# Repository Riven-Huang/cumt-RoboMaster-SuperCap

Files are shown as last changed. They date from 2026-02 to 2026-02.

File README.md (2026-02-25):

<div align="center">



[]()
[]()

**双向拓扑超级电容管理系统** | Bidirectional Buck-Boost Super Capacitor Management System

</div>

## 项目简介

本项目是中国矿业大学（CUMT）Cubot战队为RoboMaster比赛设计的**双向拓扑超级电容管理系统**。该系统用于舵轮步兵与摩擦轮英雄机器人，旨在提高规则允许下的闲置功率利用率。

---

## 🏗️ 硬件说明

### 📦 硬件实物图

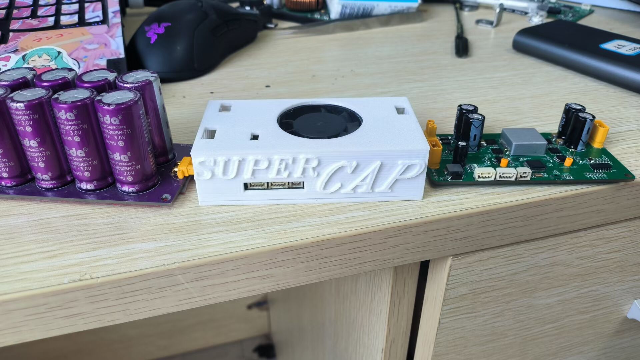
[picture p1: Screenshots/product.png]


### 核心功能

- **双向DC-DC转换**: Buck-Boost拓扑，支持充电和放电模式
- **功率管理**: 多环PID控制（电压环、电流环、功率环）
- **智能模式切换**: 基于占空比的平滑模式切换
- **CAN通信**: 与RoboMaster主控板实时通信
- **故障保护**: 过压、欠压、过流、短路保护

### 技术规格

| 参数 | 规格 |
|---|---|
| 主控芯片 | STM32F334C8Tx |
| PWM频率 | HRTIM 46.08kHz |
| 输入电压 | 24V (电池) |
| 电容电压 | 26V (目标) |
| 最大充电功率 | 200W |
| 控制方式 | 数字控制 (PID) |

---

## 2. 许可证说明

本项目采用 **CERN-OHL-S v2** (CERN Open Hardware Licence - Strongly Reciprocal) 开源许可证。

### 2.1 许可证权利

- ✅ 可自由使用、复制、修改本项目
- ✅ 可用于商业产品开发
- ✅ 可分发本项目及其衍生产品

### 2.2 许可证义务

- ⚠️ 分发时必须使用相同的 CERN-OHL-S v2 许可证
- ⚠️ 如果创建基于本项目的衍生产品，必须开源源代码
- ⚠️ 不得使用CERN的名称或标识进行商业背书
- ⚠️ 本项目按"原样"提供，无任何担保

### 2.3 第三方组件

| 组件 | 许可证 | 说明 |
|---|---|---|
| STM32 HAL库 | BSD-3-Clause | ST官方提供 |
| CMSIS | Apache 2.0 | ARM官方提供 |

---

## 3. 项目结构

```
cumt-RoboMaster-SuperCap/
├── LICENSE                    # CERN-OHL-S v2 许可证全文
├── README.md                  # 项目说明
│
├── Code Project/              # 代码项目
│   └── CAP_Code钳位/
│       ├── Core/              # CubeMX生成代码
│       │   ├── Inc/           # 头文件
│       │   └── Src/           # 源文件 (main.c, adc.c, can.c, etc.)
│       ├── MDK-ARM/           # Keil工程
│       │   └── bsp_user/      # 用户驱动层
│       │       ├── function.c/h   # 核心控制逻辑
│       │       ├── drv_can.c/h    # CAN通信驱动
│       │       ├── drv_pid.c/h    # PID控制器
│       │       ├── power_calc.c/h # 功率计算
│       │       ├── filter.c/h     # 滤波算法
│       │       └── drv_usart.c/h # 串口调试
│       ├── Drivers/           # STM32 HAL库
│       └── F334_series.ioc    # CubeMX配置文件
│
├── PCB Project/               # PCB设计文件
│   └── banzang电容_2023-06-19.epro  # 立创EDA工程
│
├── Gerber制版文件/           # PCB制造文件 (Gerber)
│
└── Screenshots/               # 产品图片
```

---

## 4. 硬件设计说明

### 4.1 拓扑结构

本项目采用**双向Buck-Boost拓扑**：

```
┌─────────┐     ┌─────────┐         ┌──────────┐
│  Battery │────▶│  Buck  │◀────▶│  Super   │
│   24V   │     │  Boost  │         │ Capacitor│
└─────────┘     │ (双向)   │        │   26V    │
                └─────────┘         └──────────┘
                      │              
                      ▼              
                ┌─────────┐     
                │ Chassis │
                │  负载   │     
                └─────────┘     
```

### 4.2 关键设计特点

1. **双向拓扑**: 使用同一套功率级实现充电和放电
2. **软启动**: 防止上电时Buck反向识别为高Boost导致炸板
3. **占空比切换**: 使用占空比判断进行模式切换，比电压判断更稳定

### 4.3 已解决问题

| 问题 | 解决方案 |
|---|---|
| 上电炸板 | 增加前馈抑制浪涌 |
| 模态切换不稳定 | 使用占空比判断代替电压判断 |

### 4.4 已知问题

| 问题 | 说明 |
|---|---|
| 9025电机适配 | 电调内部TVS可能烧毁 |
| 屏蔽电感 | 建议更换为磁环电感以提高耐流 |

---

## 5. 软件架构

### 5.1 控制流程

```
┌─────────────────┐
│   CAN接收       │ ← 接收主控功率指令
└────────┬────────┘
         ▼
┌─────────────────┐
│  功率计算       │ ← ADC采样电压/电流
└────────┬────────┘
         ▼
┌─────────────────┐
│  功率环PID      │ ← 目标功率 vs 实际功率
└────────┬────────┘
         ▼
┌─────────────────┐
│  模式判断       │ ← Buck / Mix / Boost
│  (BBMode)       │
└────────┬────────┘
         ▼
┌─────────────────┐
│  方向判断       │ ← 充电 / 放电
│  (DRMode)       │
└────────┬────────┘
         ▼
┌─────────────────┐
│  状态机         │ ← Init / Wait / Rise / Run / Err
│  (StateM)       │
└────────┬────────┘
         ▼
┌─────────────────┐
│  HRTIM PWM输出  │ ← 控制功率MOS
└─────────────────┘
```

### 5.2 主要模块

| 模块 | 功能 |
|---|---|
| `function.c` | 核心控制逻辑、状态机、模式切换 |
| `drv_pid.c` | PID控制器实现 |
| `drv_can.c` | CAN通信（接收功率指令、发送电容状态） |
| `power_calc.c` | ADC采样、功率计算 |
| `filter.c` | 数字滤波算法 |

---

## 6. 快速开始

### 开发环境

- **IDE**: Keil MDK-ARM
- **CubeMX**: STM32CubeMX (用于配置)
- **编译器**: ARM GCC 或 ARMCC

### 编译步骤

1. 使用 Keil 打开 `F334_series.uvprojx` 工程文件
2. 选择目标芯片: STM32F334C8Tx
3. 编译项目生成 hex 文件
4. 使用 JLink 或 ST-Link 烧录到芯片

### ⚠️ 注意事项

- 代码中的ADC拟合参数需要根据实际采样芯片重新校准。不同批次的采样芯片可能存在偏差。
- 建议使用磁环电感以提高耐流能力。

---

## 7. 调试记录

1. ✅ 上电炸板问题 - 已解决 (增加前馈抑制浪涌)
2. ✅ 模态切换不稳定 - 已解决 (使用占空比钳位判断)
3. ⚠️ 9025电机适配 - 未解决 
4. ⚠️ 屏蔽电感耐流 - 建议更换为磁环电感

---

## 8. 贡献指南

欢迎提交Issue和Pull Request！

### 提交规范

1. 提交前请确保代码可以正常编译
2. 添加适当的注释说明
3. 保持代码风格一致

### 问题反馈

如发现问题或有改进建议，请在GitHub仓库中提交Issue。

---

## 9. 免责声明

本项目按"原样"提供，不提供任何明示或暗示的保证，包括但不限于：
- 适销性保证
- 特定用途适用性保证
- 非侵权保证

使用者应自行承担使用本项目的风险。

---

**本项目基于 CERN-OHL-S v2 许可证开源**

Copyright (C) 2023 Riven

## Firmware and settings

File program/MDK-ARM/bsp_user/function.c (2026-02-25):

#include "function.h"


struct _Ctr_value CtrValue = { 0.0f, 0.0f, 30.0f, 0.0f, 0 ,MIN_BUCK_DUTY, 0, 0, 0 }; //控制参数
struct _FLAG FLAGS = { 0, 0, 0, 0, 0, 0, 0, 0, 0, 0, 0 }; //控制标志位




/** ===================================================================
 **     Funtion Name :void BBMode(void)
 **     Description :运行模式判断
 **      Buck模式：输出参考电压<0.8倍输入电压
 **      MIX模式：1.2倍输入电压>输出参考电压>0.8倍输入电压
 **      当进入MIX（buck-boost）模式后，退出到 Buck时需要滞缓，防止在临界点来回振荡
 **     Parameters  :
 **     Returns     :
 ** ===================================================================
*/

void BBMode(void)
{
    // 上一次模式状态量
    uint8_t PreBBFlag = 0;

    // 暂存当前的模式状态量
    PreBBFlag = FLAGS.BBFlag;
    switch (FLAGS.BBFlag)
    {
    // NA
    case NA0:
    {
        /*init control value*/
        CtrValue.Voref = tarvoltage;
        CtrValue.Poref = 30.0f;
        // power ref will change in CAN_receive file, HAL_FDCAN_RxFifo0Callback function

        if (cap.V < (in.V * 0.8f)) // vout < 0.8 * vin
        {
            FLAGS.BBFlag = Buck; // buck mode
        }
        else
        {
            FLAGS.BBFlag = Mix; // buck-boost mode
        }
        break;
    }
    // Buck模式
    case Buck:
    {
        if (pid_final_buck >= 0.83f) // vout > 0.85 * vin
        {
            FLAGS.BBFlag = Mix; // buck-boost mode
        }
        break;
    }
    // Mix模式
    case Mix:
    {
        if (pid_final_boost <= 0.05f) // vout < 0.8 * vin
        {
            FLAGS.BBFlag = Buck; // buck mode
        }
        break;
    }
    }
    // when mode changes, set reg
    if (PreBBFlag != FLAGS.BBFlag)
        FLAGS.BBModeChange = 1;
		else
			  FLAGS.BBModeChange = 0;

}

/** ===================================================================
 **     Function Name :void DRMode(void)
 **     Description:currnt direction judge
 **     Charge mode:battery charges cap
 **     Discharge mode:cap discharge power to chassis
 **     when get into Discharge mode,exits need to put in a delay,in order to avoid oscillating
 **     Parameters  :
 **     Returns     :
 ** ===================================================================*/
void DRMode(void)
{
    //last dr mode
    uint8_t PreDRFlag = 0;

    //save current dr mode
    PreDRFlag = FLAGS.DRFlag;

    /*full_bridge_in.I = c_in.value_elec - c_chassis.value_elec;*/
    switch (FLAGS.DRFlag)
    {
    //PID set - ref, when over power, error is below 0
    //NA
    case NA1:
    {
        if (powerin_Ploop.output >= 0)
        {
            FLAGS.DRFlag = Charge;     //charge mode
        }
        else
        {
            FLAGS.DRFlag = Discharge;  //Discharge mode
        }
        break;
    }
        // charge mode
    case Charge:
    {
			LED_ON(RED);
			LED_OFF(BLUE);
        if (powerin_Ploop.output < 0)
        {
            FLAGS.DRFlag = Discharge;  //Discharge mode
        }
        break;
    }
        //discharge mode
    case Discharge:
    {
			LED_OFF(RED);
			LED_ON(BLUE);
        if (powerin_Ploop.output >= 0)
        {
            FLAGS.DRFlag = Charge;     //charge mode
        }
        break;
    }
    }
    //when mode changes,set reg
    if (PreDRFlag != FLAGS.DRFlag)
        FLAGS.DRModeChange = 1;
//    else
//        FLAGS.DRModeChange = 0;

}

/** ===================================================================
 **     Funtion Name :void LED_xx(enum _LED_Color LED_Color)
 **     Description :LED切换
 **     Parameters  :
 **     Returns     :
 ** ===================================================================*/

void LED_ON(enum _LED_Color LED_Color)
{
	if      (LED_Color == GREEN){HAL_GPIO_WritePin(GPIOA,GPIO_PIN_15,GPIO_PIN_RESET);}//设置GPIO引脚电平}
	else if (LED_Color == RED)  {HAL_GPIO_WritePin(GPIOB,GPIO_PIN_5, GPIO_PIN_RESET);}
	else if (LED_Color == BLUE) {HAL_GPIO_WritePin(GPIOB,GPIO_PIN_6,GPIO_PIN_RESET);}
}
	
void LED_OFF(enum _LED_Color LED_Color)
{
	if      (LED_Color == GREEN){HAL_GPIO_WritePin(GPIOA,GPIO_PIN_15,GPIO_PIN_SET);}
	else if (LED_Color == RED)  {HAL_GPIO_WritePin(GPIOB,GPIO_PIN_5, GPIO_PIN_SET);}
	else if (LED_Color == BLUE) {HAL_GPIO_WritePin(GPIOB,GPIO_PIN_6,GPIO_PIN_SET);}
}

void LED_Toggle(enum _LED_Color LED_Color)
{
	if      (LED_Color == GREEN){HAL_GPIO_TogglePin(GPIOA,GPIO_PIN_15);}
	else if (LED_Color == RED)  {HAL_GPIO_TogglePin(GPIOB,GPIO_PIN_5) ;}
	else if (LED_Color == BLUE) {HAL_GPIO_TogglePin(GPIOB,GPIO_PIN_6) ;}
}


/** ===================================================================
 **     Function Name :void StateM(void)
 **     Description :   状态机函数
 **                     state machine function
 **     初始化状态
 **     initial state
 **     等外启动状态
 **     wait state
 **     启动状态
 **     rise state
 **     运行状态
 **     run state
 **     故障状态
 **     error state
 **     Parameters  :
 **     Returns     :
 ** ===================================================================*/
//软启动状态标志位
SState_M STState = SSInit;

void StateM(void)
{
    //判断状态类型
    //judge state type
    switch (FLAGS.SMFlag)
    {
    //初始化状态
    case Init:
        StateMInit();
        break;
        //等待状态
    case Wait:
        StateMWait();
        break;
        //软启动状态
    case Rise:
        StateMRise();
        break;
        //运行状态
    case Run:
        StateMRun();
        break;
        //故障状态
    case Err:
        StateMErr();
        break;
    }
}


/** ===================================================================
 **     Function Name :void StateMInit(void)
 **     Description :   初始化状态函数，参数初始化
 **                     initial function, parameter initialed
 **     Parameters  :
 **     Returns     :
 ** ===================================================================*/
void StateMInit(void)
{
    //相关参数初始化
    //initial relative parameter
    ValueInit();
    //状态机跳转至等待软启状态
    //go to wait state waiting for rise state
    FLAGS.SMFlag = Wait;
}

/** ===================================================================
 **     Function Name :void StateMWait(void)
 **     Description :   等待状态机，等待1S后无故障则软启
 **                     wait state, wait for 1s to start when there is no error
 **     Parameters  :
 **     Returns     :
 ** ===================================================================*/
void StateMWait(void)
{
    //计数器定义
    //counter
    static uint16_t CntS = 0;

    //关PWM
    //shutdown PWM
    FLAGS.PWMENFlag = 0;
    //计数器累加
    //counter add
    CntS++;
    //等待1ms*200，进入启动状态
    //wait for 1ms*200, entering rise state
    if (CntS > 256)
    {
        CntS = 256;

        if (FLAGS.ErrFlag == F_NOERR)
        {
            //计数器清0
            //counter reset to zero
            CntS = 0;
            //状态标志位跳转至等待状态
            //state flag go 2 wait state
            FLAGS.SMFlag = Rise;
            //软启动子状态跳转至初始化状态
            //soft start(rise state) go 2 initial state
            STState = SSInit;
        }
    }
}
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

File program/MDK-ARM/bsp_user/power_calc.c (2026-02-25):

#include "power_calc.h"
#include "drv_pid.h"

struct ParameterBridge dcdcinfo;
struct ParameterBridge dcdctest;

/** ===================================================================
 **     Funtion Name :void UserADC1_Init(void)
 ** 
 **     Description :ADC1用户初始化函数，DMA/IT/轮询
 **                   
 **     Parameters  :
 **     Returns     :
 ** ===================================================================*/
 
/*----------ADC初始化----------*/
uint32_t UserADC1_ConvertedValue[ADC1_CHANNEL_FRE][ADC1_CHANNEL_CNT]={0};
void UserADC1_Init(void)
{
	HAL_ADCEx_Calibration_Start(&hadc1,ADC_SINGLE_ENDED);
	HAL_Delay(10);
	//ADC_Enable(&hadc1);
	HAL_ADC_Start_DMA(&hadc1,(uint32_t *)UserADC1_ConvertedValue,ADC1_CHANNEL_FRE*ADC1_CHANNEL_CNT);
  //HAL_ADC_Start_IT(&hadc1);
}


/** ===================================================================
 **     Funtion Name :void HAL_ADC_ConvCpltCallback(ADC_HandleTypeDef* hadc)
 **  									-weak-
 **     Description :ADC采样完成弱回调函数,线性计算ADC采样数据
 **									 在该函数中进行滤波与线性计算，计算过程关闭中断
 **                   
 **     Parameters  :
 **     Returns     :
 ** ===================================================================*/

float adc_raw_data[ADC1_CHANNEL_CNT];
uint32_t usefor_adc[ADC1_CHANNEL_CNT];
/*-weak-*/void HAL_ADC_ConvCpltCallback(ADC_HandleTypeDef* hadc)
{
	for (uint8_t j = 0; j < ADC1_CHANNEL_CNT; j++) 
	{
    for (uint8_t i = 0; i < ADC1_CHANNEL_FRE; i++) 
		{
      adc_raw_data[j] += UserADC1_ConvertedValue[i][j];
    }
    adc_raw_data[j] /= ADC1_CHANNEL_FRE; // 取平均值
  }
	  for (uint8_t i = 0; i < ADC1_CHANNEL_CNT; i++) 
	  {
      usefor_adc[i] = adc_raw_data[i];
    }
	
#if board_version == 0
	dcdcinfo.V_bat =    	  (float)adc_raw_data[0]* 0.0121f   + 0.0407f;
	dcdcinfo.V_cap =     		(float)adc_raw_data[1]* 0.0120f   + 0.0283f;
//	dcdcinfo.I_cap_in =     (float)adc_raw_data[2]* (-0.0053f)   +10.7935f;
	dcdcinfo.I_cap_in=      (float)adc_raw_data[2]* (-0.0021f)   +4.3374f;
	dcdcinfo.I_cap_out = 		(float)adc_raw_data[3]* 0.0053f   -10.8435f;
	dcdcinfo.I_bat =  			(float)adc_raw_data[4]* 0.0053f   -10.7935f;
	
#endif
	  for (uint8_t i = 0; i < ADC1_CHANNEL_CNT; i++) 
		{
      adc_raw_data[i] = 0;
    }
/*--IN3_VBAT,IN4_VCAP,IN11_IBAT,IN12_ICAPout,IN13_ICAPin--*/
		control_calc();
		adcProtcnt++;
}



/*
 ** ===================================================================
 **     Funtion Name : void control_calc(float plim)
 **     Description :  计算回路中四点参数
 **     Parameters  :无	
 **                 none
 **     Returns     :无
 **                 none
 ** ===================================================================
 */
CONTROL_STRUCT in, chassis, full_bridge_in, cap; //总输入，底盘输出，dcdc输入，dcdc输出
void control_calc(void)
{
#if LPF_ENABLE == 1
    lpf[0].Input = dcdcinfo.I_bat;
    lpf[1].Input = dcdcinfo.V_bat;
    lpf[2].Input = dcdcinfo.I_cap_in;
    lpf[3].Input = dcdcinfo.I_cap_out;
    lpf[4].Input = dcdcinfo.V_cap;
	
    for (char i = 0; i < 5; i++)
    {
        low_filter_calc(&lpf[i]);
    }
		
		dcdctest.I_bat = lpf[0].Output;
		dcdctest.V_bat = lpf[1].Output;
		dcdctest.I_cap_in = lpf[2].Output;
		dcdctest.I_cap_out = lpf[3].Output;
		dcdctest.V_cap = lpf[4].Output;
		
		in.I = dcdctest.I_bat;
		in.V = dcdctest.V_bat;
		in.P = in.V * in.I;
		if(in.P<0){in.P = 0;}
		
		chassis.I = dcdctest.I_bat - dcdctest.I_cap_in;
		chassis.V = dcdctest.V_bat;
		chassis.P = chassis.V * chassis.I;
		
		full_bridge_in.I = dcdctest.I_cap_in;
		full_bridge_in.V = dcdctest.V_bat;
		full_bridge_in.P = full_bridge_in.V * full_bridge_in.I;
		
		cap.I = dcdctest.I_cap_out;
		cap.V = dcdctest.V_cap;
		cap.P = cap.V * cap.I;
	
#else
		in.I = dcdcinfo.I_bat;
		in.V = dcdcinfo.V_bat;
		in.P = in.V * in.I;
		if(in.P<0){in.P = 0;}
		
		chassis.I = dcdcinfo.I_bat - dcdcinfo.I_cap_in;
		chassis.V = dcdcinfo.V_bat;
		chassis.P = chassis.V * chassis.I;
		
		full_bridge_in.I = dcdcinfo.I_cap_in;
		full_bridge_in.V = dcdcinfo.V_bat;
		full_bridge_in.P = full_bridge_in.V * full_bridge_in.I;
		
		cap.I = dcdcinfo.I_cap_out;
		cap.V = dcdcinfo.V_cap;
		cap.P = cap.V * cap.I;
#endif
}

/*
 ** ===================================================================
 **     Funtion Name : void BuckBoostVLoopCtlPID(void)
 **     Description :  BUCK-BOOST模式下环路计算
 **                    BUCK-BOOST mode loop calculate
 **     检测输出参考电压与输入电压的关系，判断环路工作于BUCK模式，还是BUCK-BOOST模式
 **     detect output reference voltage's relationship with input voltage,
 **     judge loop control mode is buck-boost mode or buck mode
 **     BUCK模式下，BOOST的开关管工作在固定占空比，控制BUCK的占空比控制输出电压
 **     in BUCK mode, boost side mosfet is work in fixed duty, buck side mosfet control output voltage
 **     BUCK-BOOST模式下，BUCK的开关管工作在固定占空比，控制BOOST的占空比控制输出电压
 **     in BUCK-BOOST mode, buck side mosfet is work in fixed duty, boost side mosfet control output voltage
 **     Parameters  :无
 **                 none
 **     Returns     :无
 **                 none
 ** ===================================================================
 */

#define shift_ratio 0.83f
float testpower = 30.0f;
float testvoltage = 25.50f;
float testI = 1.3f;
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
